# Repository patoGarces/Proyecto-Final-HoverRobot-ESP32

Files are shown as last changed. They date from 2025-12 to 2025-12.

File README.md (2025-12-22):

<h1 align="center">Universidad Nacional de Lomas de Zamora - Facultad de Ingeniería</h1>

Logo Institucional

<h1 align="center">HoverRobot ESP32</h1>

<p align="center">
  <br>
  <em>Estabilización y control</em>
</p>

<p align="center">
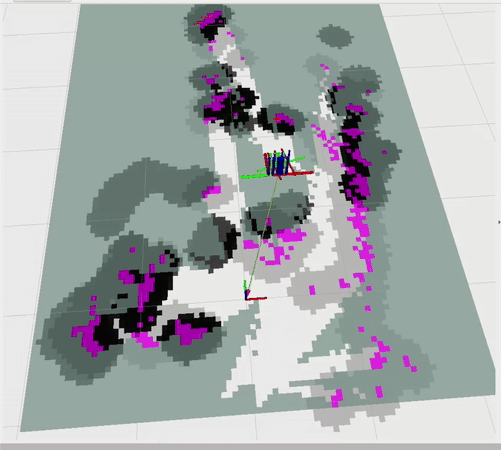
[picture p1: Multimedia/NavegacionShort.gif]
  <br>
  <em>Navegación autónoma con ROS2</em>
</p>

<p align="center">
  <a href="https://www.youtube.com/watch?v=PdzagmnXbF4" target="_blank">
    
  </a>
  <br>
  <em>Demo HoverRobot</em>
</p>

## Introducción / Objetivo

La **Facultad de Ingeniería de la UNLZ** promueve proyectos orientados a la robótica, control y automatización.  
Este repositorio corresponde al **Proyecto Final de Ingeniería Mecatrónica**, cuyo desarrollo se centra en un robot de balanceo autónomo denominado **HoverRobot ESP32**.

El objetivo principal es **convertir la estructura de un hoverboard en una plataforma robótica inteligente**, integrando:

- Un **sistema de control dinámico** basado en **ESP32**.  
- Un **sensor inercial** para mantener el equilibrio.  
- Un módulo de **visión estéreo** basado en una **cámara PS5 + Raspberry Pi 5**.  
- Una **aplicación móvil** para control manual.  

El proyecto explora la interacción entre **estabilidad dinámica**, **visión en tiempo real** y **navegación autónoma** mediante ROS 2.

---

## Índice

- [Descripción](#descripción)
- [Alcance y estado actual](alcance-y-estado-actual)
- [Arquitectura general](#arquitectura-general)
- [Planificación](#planificación)
- [Tecnologías Utilizadas](tecnologias-utilizadas)
- [Listado de Componentes](#listado-de-componentes)
- [Cálculos](#cálculos)
- [Esquemáticos](#esquemáticos)
- [Diseño mecánico y planos](#diseño-mecánico-y-planos)
- [Instrucciones de Uso](#instrucciones-de-uso)  
- [Autor](#autor)  
- [Repositorios Relacionados](#repositorios-relacionados)

---

## Descripción

**HoverRobot** es un robot autoequilibrado que combina electrónica embebida, control dinámico y visión computacional.  
El proyecto nace como una plataforma de estudio para integrar conocimientos de **control**, **electrónica**, **visión artificial**, y **robótica móvil**, culminando en un prototipo **totalmente funcional** y con navegación reactiva para evasión de obstáculos.

---

## Alcance y estado actual

### Objetivos logrados

- Robot de balanceo totalmente funcional.
- Deteccion de profundidad a partir de una camara stereo
- Control manual mediante app móvil.  
- Comunicación estable entre todos los subsistemas.
- Mapeo 2D real mediante SLAM.  
- Navegación basada en visión estéreo. 
- Pruebas en entornos reales con detección de obstáculos.

### Limitaciones actuales y oportunidades de mejora

- El **mapa presenta drift acumulado**, principalmente por la ausencia de un **magnetómetro**, lo que afecta la estabilidad del yaw en la odometría visual.  
- El **campo de visión reducido** de la cámara PS5 limita la cantidad de características detectables, afectando el desempeño del **scan matching de slam_toolbox** y reduciendo la calidad del mapeo.  
- El control basado en PID, aunque funcional, no se adapta automáticamente a variaciones en la dinámica del robot (cambios de peso, centro de gravedad, carga o variaciones en la tracción efectiva de las ruedas). Como mejora futura, podrían evaluarse métodos más robustos como LQR, MPC, control adaptativo o gain scheduling.

---

## Arquitectura general

El sistema se compone de tres subsistemas principales:

### 1. Control de balanceo (ESP32)

- Placa electrónica personalizada con **ESP32**.  
- Lectura de un **IMU MPU6050** para estimar la inclinación del robot.  
- Control directo de los **motores brushless** del hoverboard.  
- Indicadores de estado mediante **WS2812 LEDs**.

### 2. Visión y navegación (Raspberry Pi + ROS 2)

- La **cámara estéreo PS5** captura imágenes del entorno.  
- La **Raspberry Pi 5** procesa la visión y ejecuta nodos ROS 2 para:
  - Rectificación estéreo  
  - Cálculo de disparidad  
  - Conversión a nube de puntos o LaserScan  
  - SLAM con *slam_toolbox*  
  - Planificación y navegación  
- Permite construir un **mapa 2D** del ambiente usando únicamente visión.

### 3. Interfaz y comunicaciones

- **Aplicación móvil en Kotlin** para control manual.  
- Comunicación **TCP** entre Raspberry Pi ↔ ESP32 ↔ App.  
- El robot funciona como **punto de acceso WiFi**, permitiendo conectarse desde una notebook para:
  - **visualizar el mapa en RViz**,  
  - **monitorear datos**,  
  - **lanzar o detener nodos ROS 2**.  

---

## Planificación

### Gantt inicial

<p align="center">
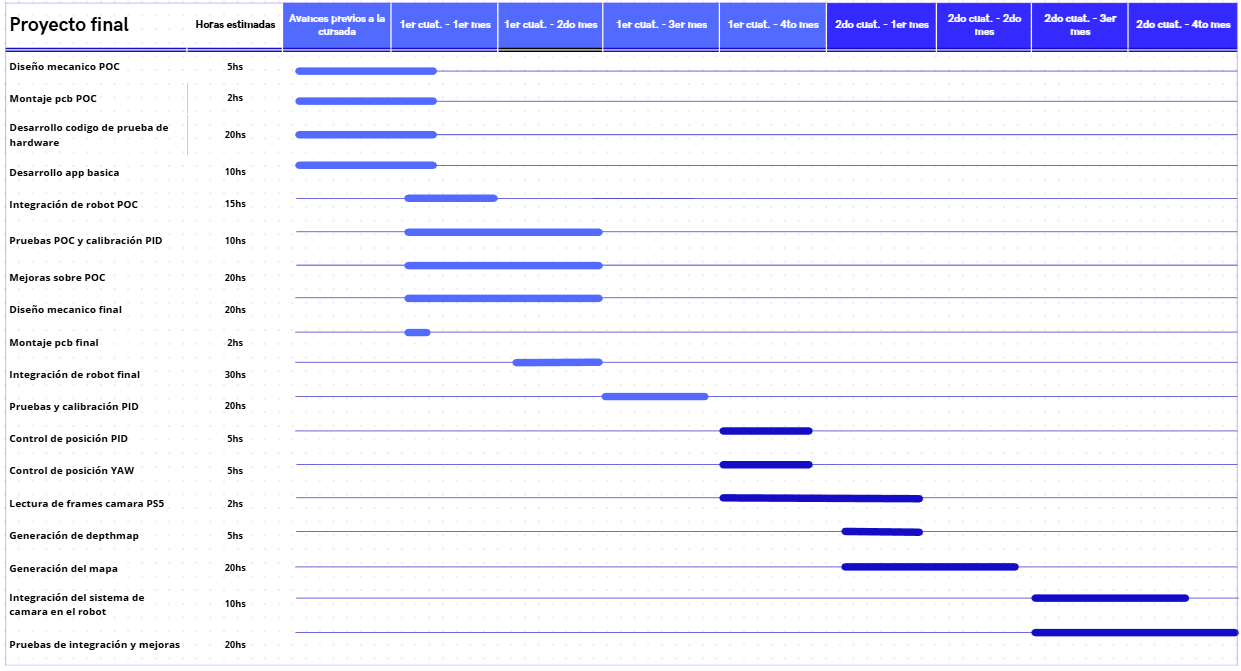
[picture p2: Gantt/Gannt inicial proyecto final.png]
  
  <em>Estimacion inicial: 221hs</em>
</p>

### Gantt final

<p align="center">
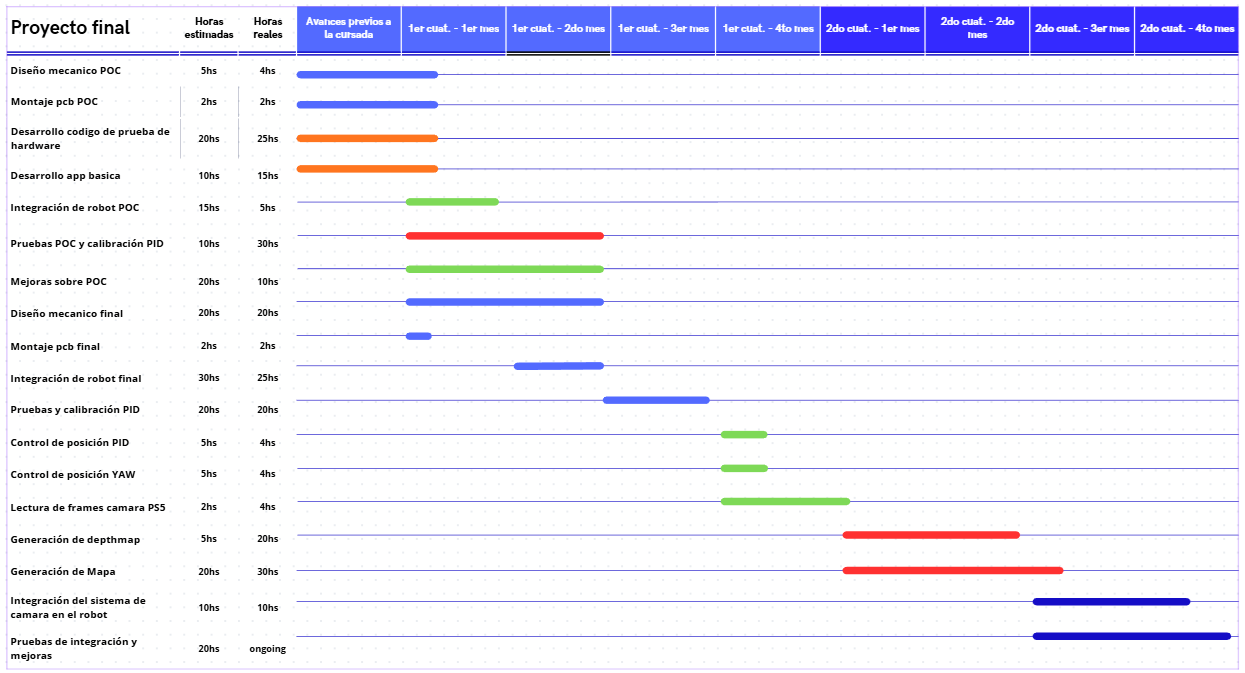
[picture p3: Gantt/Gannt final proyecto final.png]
  
  <em>Total de horas reales: 230hs + ongoing</em>
</p>

Si bien la estimación global fue cercana a la real, algunas tareas puntuales presentaron desvíos significativos debido a problemas técnicos no previstos, cuya resolución demandó más tiempo del estimado inicial.
Estos desvíos se compensaron con otras tareas que resultaron menos complejas de lo esperado.

### Desvío total: +9 h respecto a la estimación inicial

---

## Tecnologías Utilizadas

- **Control y Robótica**: ESP32, controladora hoverboard, motores brushless  
- **Sensado**: IMU MPU6050, cámara estéreo PS5  
- **Computación / Procesamiento**: Raspberry Pi 5, Python, C, Kotlin  
- **Frameworks**: ROS 2 (Jazzy), OpenCV, freeRTOS
- **Comunicación**: TCP sockets, UART  
- **Visión Artificial**: extracción de características, flujo estéreo, navegación basada en percepción  

---

## Listado de Componentes  

### 1. Electrónica del robot (control, regulación, sensores)
| Componente | Cantidad | Precio Unitario (USD) | Precio Total (USD) | Notas |
|---|---|---|---|---|
| ESP32 (montado en placa custom) | 1 | 8 | 8 | Microcontrolador principal |
| Placa perforada / PCB prototipo (custom) | 1 | 3.5 | 3.5 | Base para montar ESP32, sensores y electrónica |
| IMU MPU6050 | 1 | 2 | 2 | Sensor de aceleración y giroscopio |
| Step Down HV | 2 | 4 | 8 | Regulación de tensión |
| Módulo LED WS2812 (8 LEDs) | 1 | 2 | 2 | Indicador de estado visual |
| Cableado + conectores | — | 10 | 10 | JST, Dupont, termocontraíble, etc. |

### 2. Hardware del robot (estructura y montaje)
| Componente | Cantidad | Precio Unitario (USD) | Precio Total (USD) | Notas |
|---|---|---|---|---|
| Hoverboard reutilizado | 1 | 30 | 30 | Motores brushless + controladora + Bateria |
| Perfiles de aluminio 40×40×200 | 2 | 3 | 6 | Estructura |
| Base de fibrofacil | 2 | 5 | 10 | Placas de montaje |
| Rollo de filamento PLA 1 kg | 1 | 12 | 12 |  |
| Tornillería variada | — | 10 | 10 | Ensamblaje |

### 3. Computadora, visión y periféricos
| Componente | Cantidad | Precio Unitario (USD) | Precio Total (USD) | Notas |
|---|---|---|---|---|
| Raspberry Pi 5 | 1 | 100 | 100 | Nodo principal ROS 2 |
| Cámara estéreo PS5 | 1 | 30 | 30 | Visión estéreo |
| Antena WiFi externa | 1 | 5 | 5 |  |
| Conversor USB–Serie | 1 | 2 | 2 | Comuniacion con Raspberry Pi |
| Cable USB-C de alimentación (para Raspberry Pi) | 1 | 5 | 5 |  |

### 4. Totales

| Categoría | Subtotal (USD) |
|---|---|
| Electrónica | 33.5 | 
| Hardware del robot | 68 |
| Computadora y visión | 142 |
| **Total general** | 243.5 |

---

## Cálculos

En la carpeta [`Calculos`](./Calculos) se documentan los principales cálculos utilizados en el proyecto, tanto a nivel de control como de hardware.

Se incluyen:
- Cálculos para la obtención de **posición, velocidad y yaw** a partir de los sensores Hall de las ruedas.
- Descripción de la **fusión del yaw** estimado por encoders con el yaw proveniente del **IMU**.
- **Memoria de cálculo del sistema de alimentación**, donde se detalla el dimensionamiento de las fuentes a partir del consumo de cada subsistema.

Esta sección complementa la implementación práctica del robot, mostrando el criterio de diseño detrás de las decisiones tomadas.

## Esquemáticos

### Mainboard
<p align="center">
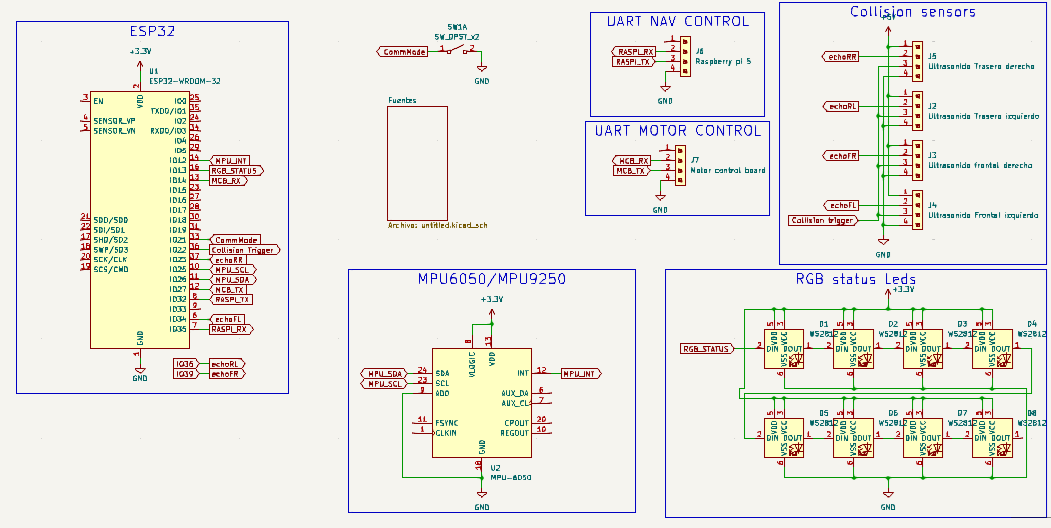
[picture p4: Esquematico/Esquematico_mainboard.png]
  <br>
  <span><em>Esquemático general de la placa de control</em></span>
</p>

### Fuentes
<p align="center">
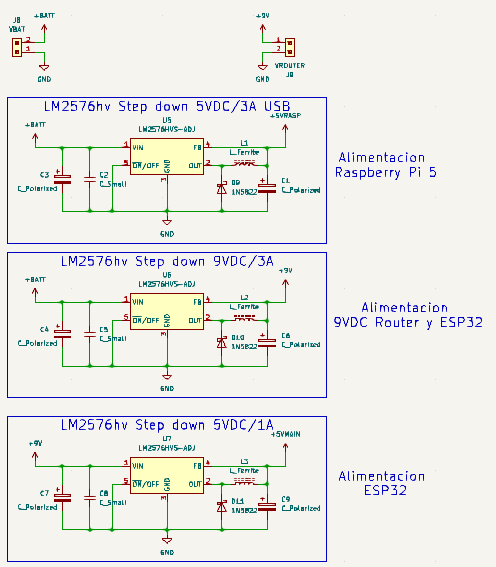
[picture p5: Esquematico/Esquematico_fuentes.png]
  <br>
  <span><em>Esquemático de las fuentes de alimentación</em></span>
</p>

---

## Diseño mecánico y planos

El diseño mecánico del robot fue desarrollado en CAD con SolidWork y documentado en archivos de fabricación, priorizando una estructura simple, modular y fácil de reproducir.

<p align="center">
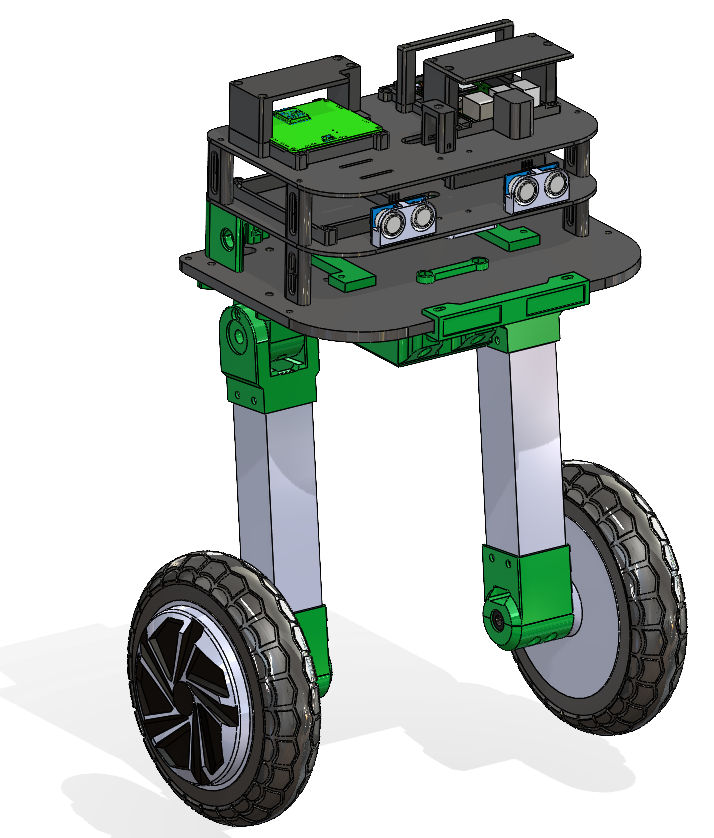
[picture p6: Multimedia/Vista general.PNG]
  <br>
  <em>Vista general del robot</em>
</p>

En el repositorio se incluyen:
- **Modelos STL** de las piezas impresas en 3D, fabricadas en **PLA**.
- **Planos 2D en PDF** para corte láser correspondientes a las **tres bases estructurales**, diseñadas en **fibrofácil**:
  - Base inferior: **9 mm** de espesor  
  - Bases superior e intermedia: **3 mm** de espesor  

Los archivos completos de diseño y fabricación se encuentran disponibles en la carpeta [Planos - 3D](Planos%20-%203D)

## Instrucciones de Uso

1. **Clonar este repositorio** y los repositorios asociados al proyecto.  
2. **Montar el hardware** siguiendo los planos y diagramas disponibles en la carpeta `Esquematico`.  
3. **Cargar el firmware del ESP32** siguiendo las instrucciones detalladas en el repositorio:  
   [HoverRobot-ESP32 (Mainboard)](https://github.com/patoGarces/HoverRobot-ESP32)
4. **Instalar y configurar la aplicación móvil**, según la guía incluida en:  
   [HoverRobotApp](https://github.com/patoGarces/HoverRobotApp-balancing-robot/)
5. **Ejecutar los nodos de visión, SLAM y navegación en ROS 2**, siguiendo los pasos del repositorio:  
   [HoverRobotNavigation](https://github.com/patoGarces/HoverRobotNavigation)
6. **Realizar pruebas** primero en entorno controlado y luego en condiciones reales, verificando estabilidad, detección de obstáculos y mapa generado.

---

## Autor

Proyecto realizado por **Patricio Garcés** como Trabajo Final de la carrera **Ingeniería Mecatrónica**,  
Facultad de Ingeniería – Universidad Nacional de Lomas de Zamora.

---

## Repositorios Relacionados  

- **Mainboard (ESP32)** → [HoverRobot-ESP32](https://github.com/patoGarces/HoverRobot-ESP32)  
- **Aplicación móvil (Kotlin)** → [HoverRobotApp-balancing-robot](https://github.com/patoGarces/HoverRobotApp-balancing-robot/)  
- **Navegación en ROS 2** → [HoverRobotNavigation](https://github.com/patoGarces/HoverRobotNavigation)
- **Firmware de la controladora (fork modificado)** → [hoverrobot-firmware-hack-FOC](https://github.com/patoGarces/hoverrobot-firmware-hack-FOC)

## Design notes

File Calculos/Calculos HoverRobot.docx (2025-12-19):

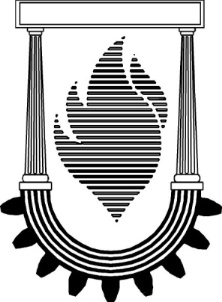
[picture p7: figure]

2° Cuatrimestre 2025

UNIVERSIDAD NACIONAL DE LOMAS DE ZAMORA

FACULTAD DE INGENIERÍA

Cálculos Proyecto Final HoverRobot

Ingeniería Mecatrónica

Alumno:

Patricio Garces (DNI: 39.919.131)

Docentes:

Ing. Cristian Leandro Lukaszewicz

Ing. Ezequiel Blanca

Ing. Juan Ignacio Szombach

# Cálculos

Cálculos a partir de sensores Hall

- Cada rueda tiene 3 sensores de efecto hall desfazados 120 grados, que proporcionan una resolución de 90 pulsos por revolución, con un diámetro de rueda de 17cm, a partir de allí se calcula la velocidad en m/s y la posición en metros:
- Distancia por revolución:

DIST_PER_REV=0.17m*π=0.5310707511m

- Conversión de posición en pasos(posHalls) a metros:

posInMeters=(posHalls)/90.00*DIST_PER_REV

- Conversión de RPM a m/s:

Velocidad [m/s]=(RPM*DIST_PER_REV)/60.00

- Conversión de m/s a RPM:

Velocidad [RPM]=(Vel(m/s)*60.00)/(DIST_PER_REV)

Cálculos eje YAW

El eje YAW, por la naturaleza del acelerómetro y del robot que se encuentra con el sensor en la base paralela al piso, solo se obtiene a partir del giróscopo, lo que genera deriva o drift, que termina afectando de manera negativa la navegación del robot, por ello, para intentar reducir esta deriva, se calcula el valor del YAW a partir de los sensores hall(Posicion) de las ruedas, para terminar fusionando ambos valores, obteniendo una mejor performance:

Para obtener el valor del Yaw(Relativo) a partir de los hall primero se debe conocer:

- Distancia entre ruedas (ancho del robot): 0.32m

Calculando:

enc_yaw_theta(rad) =enc_yaw_theta+((posInMetersR-posInMetersRant)-(posInMetersL-posInMetersLant))/(0.32m)

Conversión a grados:
enc_yaw_theta(rad)=enc_yaw_tetha(rad)* 180.00/π

Fusión de sensores:

- Primero se debe establecer una ponderación entre ambas medidas, en mi caso confío más en la medición del IMU, por lo que le doy una ponderación del 90%: FUSE_APHA_YAW = 0.9

Entonces se calcula:

actualYaw =FUSE_ALPHA_YAW* imuYaw+(1.00-FUSE_ALPHA_YAW)*enc_yaw_theta

Cálculo y Dimensionamiento del Sistema de Alimentación

El sistema utiliza una batería principal de 42 V, por lo que fue necesario diseñar una etapa de regulación capaz de alimentar de forma estable los distintos subsistemas del robot.

Con el objetivo de mejorar la estabilidad y aislar cargas críticas, se decidió dividir la alimentación en dos fuentes independientes, ambas basadas en reguladores de tipo step down:

- Fuente 1: Raspberry Pi 5 + cámara estéreo PS5
- Fuente 2: Electrónica auxiliar (ESP32, router WiFi, LEDs y sensores)

Fuente 1 – Alimentación de Raspberry Pi 5 y cámara estéreo

Consumo Raspberry Pi 5

- Tensión de alimentación: 5 V
- Corriente máxima especificada: 5 A (este valor contempla el consumo máximo incluyendo periféricos USB).

Potencia máxima teórica:

P = V × I

P = 5 V × 5 A = 25 W

Consumo cámara estéreo PS5

- Tensión de alimentación: 5 V
- Corriente estimada: 500 mA

Potencia:

P = 5 V × 0.5 A = 2.5 W

Consumo total teórico Fuente 1

Potencia total:

25 W + 2.5 W = 27.5 W

Corriente equivalente a 5 V:

I = 27.5 W / 5 V = 5.5 A

La cámara estéreo se alimenta desde la misma fuente, considerando que su consumo forma parte del consumo total de corriente de la Raspberry Pi.

Mediciones reales de consumo

Durante las pruebas del sistema se realizaron mediciones directas de corriente en la línea de 5 V, observándose que:

- El consumo real de la Raspberry Pi 5 no superó los 3 A en ningún escenario, incluso con procesamiento de visión activo.
- El consumo de la cámara (~500 mA) se encuentra incluido dentro del margen operativo observado.

Esto confirma que el consumo real es significativamente menor al valor máximo teórico indicado por el fabricante.

Selección del regulador y limitaciones

Para esta fuente se utilizó un módulo basado en LM2576HV, seleccionado principalmente por:

- Su capacidad de soportar tensiones de entrada elevadas (42 V)
- Disponibilidad comercial en formato módulo.

Si bien el consumo real medido se mantiene por debajo de este umbral, el regulador opera cerca de su límite teórico, especialmente considerando:

- La alta relación entre tensión de entrada y salida
- La disipación térmica involucrada.

Este regulador no es el ideal, pero en base a lo disponible en el mercado local, y validado mediante la medición del consumo real, se decidió utilizarlo de todas maneras ante la falta de mejores opciones.

Fuente 2 – Alimentación de la placa principal del robot y los periféricos

Cálculo teórico de consumo:

Router WiFi

- Tensión: 9 V
- Corriente: 600 mA

Potencia:

P = 9 V × 0.6 A = 5.4 W

ESP32 (con WiFi activo)

- Tensión: 5 V
- Corriente pico estimada: 500 mA

Potencia máxima:

P = 5 V × 0.5 A = 2.5 W

Tira de leds WS2812 (8 leds)

- Tensión: 5 V
- Corriente máxima por LED: 60 mA

Corriente total:

I = 8 × 60 mA = 480 mA

Potencia:

P = 5 V × 0.48 A = 2.4 W

Sensores ultrasónicos (4 en total)

- Tensión: 5 V
- Corriente por sensor: 15 mA

Corriente total:

I = 4 × 15 mA = 60 mA

Potencia:

P = 5 V × 0.06 A = 0.3 W

Resumen de consumo Fuente 2

Dispositivo | Potencia aproximada
Router WiFi | 5.4 W
ESP32 | 2.5 W
WS2812 (8 LEDs) | 2.4 W
Sensores ultrasónicos | 0.3 W
Total | 10.6 W

Corriente equivalente a 5 V:

I = 10.6 W / 5 V ≈ 2.1 A

Mediciones reales de consumo

Durante la operación normal del sistema se observó que:

- El ESP32 rara vez alcanza su corriente pico.
- Los LEDs no operan permanentemente al 100 % de brillo
- El consumo total se mantiene por debajo del escenario máximo calculado.

Las mediciones confirmaron un margen adecuado respecto a la capacidad del regulador.

Selección del regulador

Para esta fuente se utilizó un segundo módulo LM2576HV, alimentado desde la batería de 42 V igual que el primero.

Conclusión general

El análisis teórico de consumos, complementado con mediciones reales, permitió validar el diseño de un sistema de alimentación dividido en dos fuentes independientes.

Esta arquitectura mejora la estabilidad del sistema, reduce interferencias entre subsistemas y se adapta a las restricciones impuestas por la alta tensión de la batería principal, utilizando componentes disponibles comercialmente.

Consumo de los motores

Metodología de medición

El consumo del sistema de tracción (compuesto por los motores, la placa de control y la batería original de hoverboard) se midió utilizando los sensores de corriente integrados en la propia placa de potencia.

Estos valores son transmitidos vía telemetría a la aplicación móvil desarrollada para el proyecto, lo que permite visualizar y registrar el consumo en tiempo real sin instrumentación externa adicional.

La medición se realizó en dos condiciones principales:

- Régimen estabilizado: con el robot manteniendo el equilibrio sin desplazamiento significativo.
- Desplazamiento: con el robot realizando movimientos controlados.

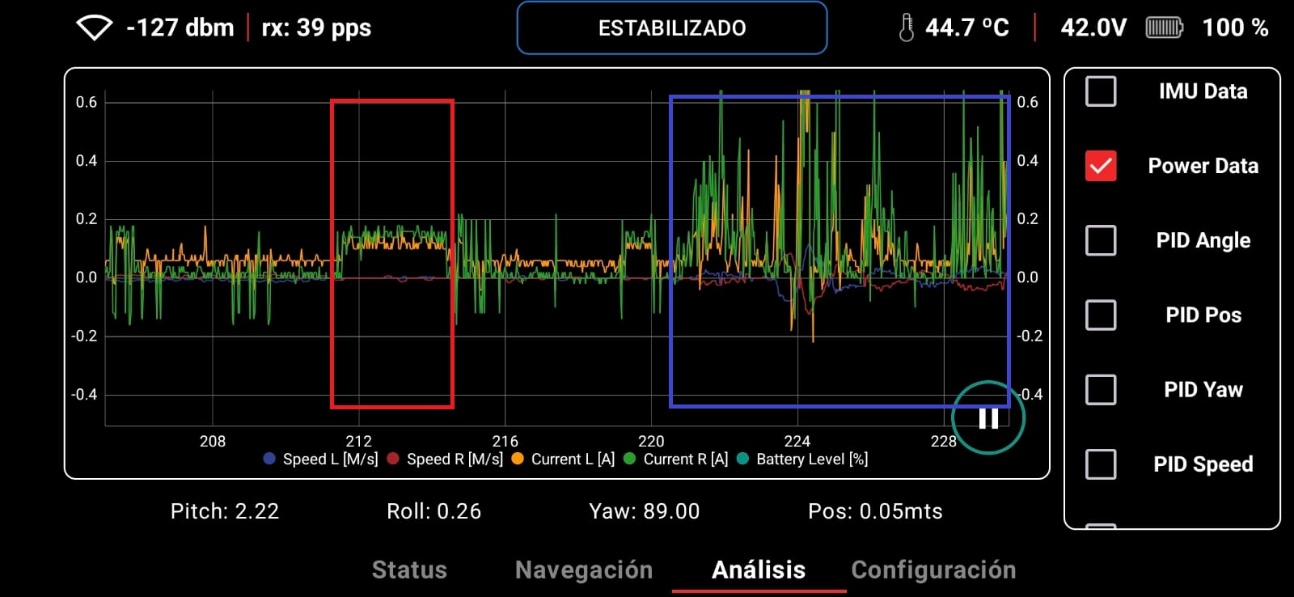
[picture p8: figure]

Gráfico de corriente en tiempo real a través de la HoverRobotApp

En la captura de la aplicación móvil, podemos apreciar:

- En rojo: Consumo correspondiente al estado de equilibrio.
- En azul: Consumo durante el desplazamiento.

En este último caso se observan principalmente picos de corriente, con una señal dominada por variaciones rápidas que se asemejan a ruido, lo que dificulta la extracción de un valor promedio representativo a partir de esa medición.

Resultados obtenidos

Durante el estado estabilizado, el consumo de corriente informado por la placa fue del orden de:

Corriente promedio en equilibrio= ~0,2 A

Potencia estimada

La potencia eléctrica consumida por el sistema de tracción en régimen estabilizado se estima como:

P=V⋅I=42V* 0.2A=8.4W

Consideraciones sobre la medición

Si bien el valor medido resulta bajo y puede generar dudas iniciales, es consistente con un escenario de equilibrio estable, sin aceleraciones ni demanda de torque elevada.

Asimismo, la medición durante el desplazamiento presenta una señal dominada por picos y variaciones rápidas, lo que sugiere limitaciones en la resolución temporal y el filtrado de la medición para ese régimen.

Para un análisis energético más detallado podrían realizarse mediciones externas del bus de potencia y bajo condiciones dinámicas controladas; sin embargo, para los objetivos de este proyecto, la caracterización del consumo en equilibrio resulta suficiente y representativa.

UNIVERSIDAD NACIONAL DE LOMAS DE ZAMORA – FACULTAD DE INGENIERÍA Proyecto final Ingeniería Mecatrónica

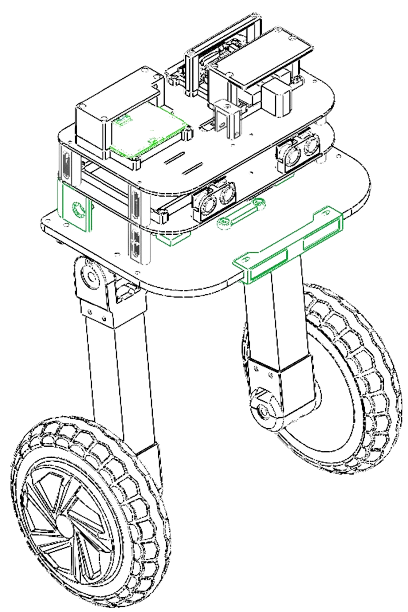
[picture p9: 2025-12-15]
Multimedia/iso_color-removebg-preview.png

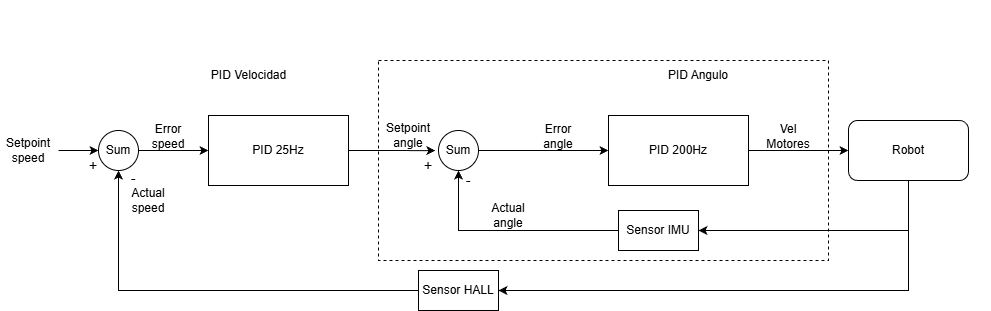
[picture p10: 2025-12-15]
Multimedia/Diagrama de control PID.png

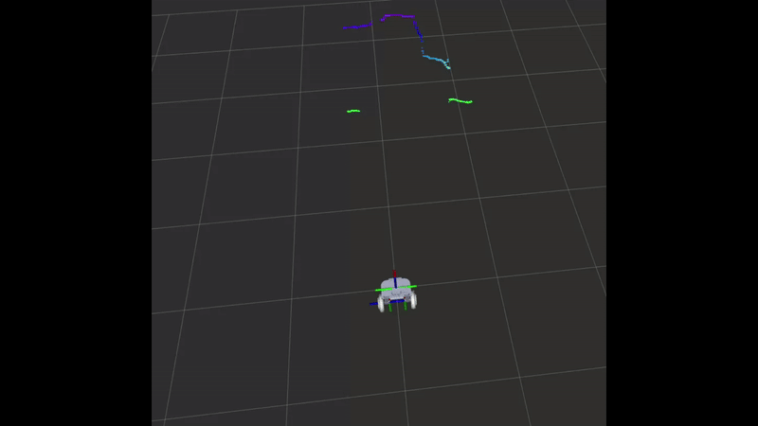
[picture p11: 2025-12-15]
Multimedia/Laserscan.gif

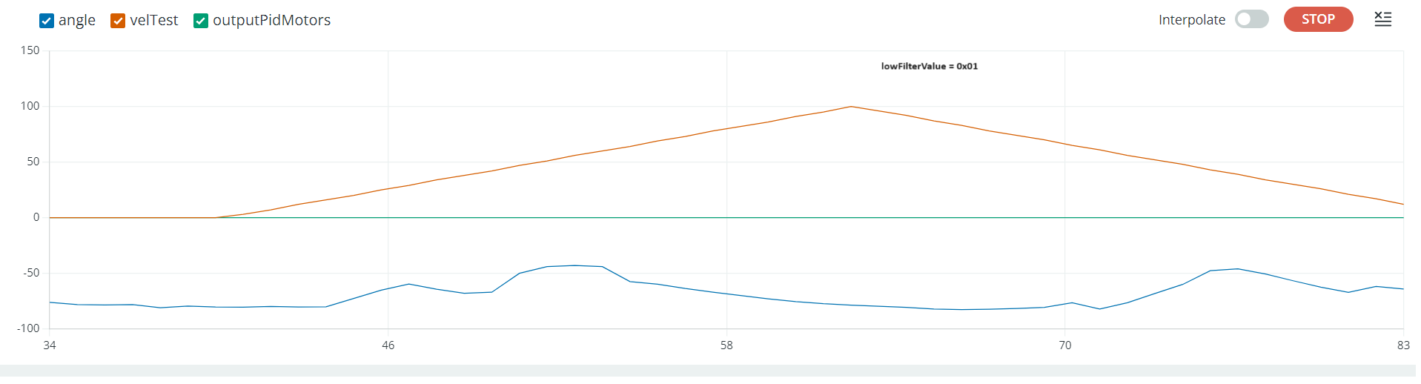
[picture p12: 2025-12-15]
Multimedia/ruido MPU6050.png

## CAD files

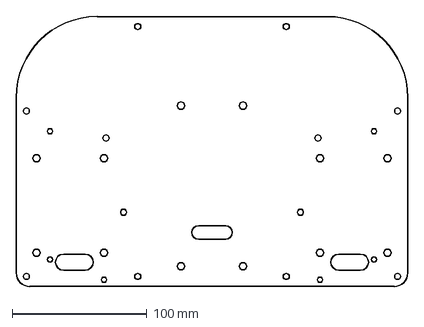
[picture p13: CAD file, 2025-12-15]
Planos - 3D/Fabricacion bases/base v1 - laser.DXF
290.0 x 200.0 mm

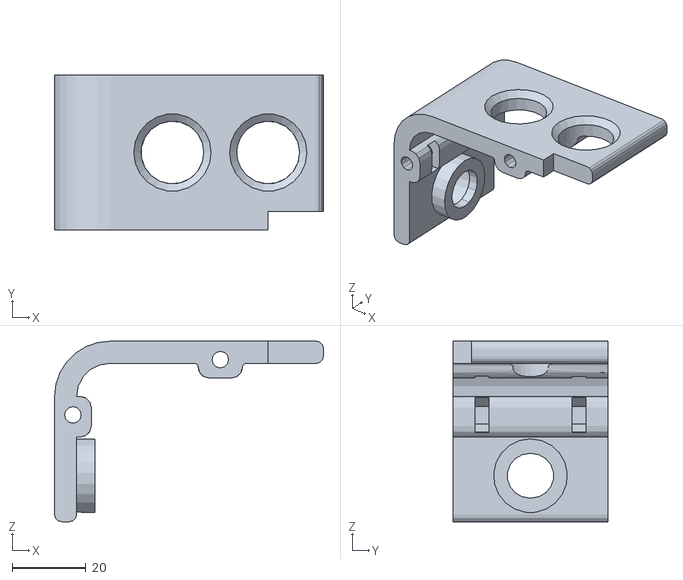
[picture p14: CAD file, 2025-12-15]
Planos - 3D/STLs/soporte lvls V2 - charger.STL
73.0 x 42.0 x 49.0

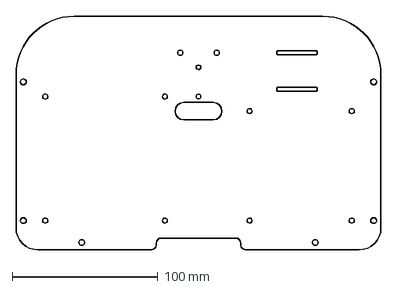
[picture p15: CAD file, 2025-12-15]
Planos - 3D/Fabricacion bases/base lvl3.DXF
250.0 x 160.0 mm

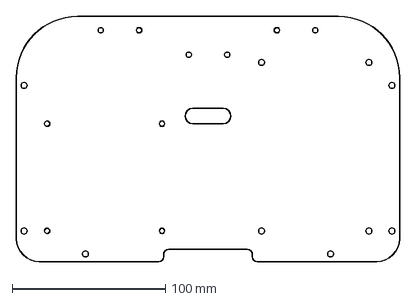
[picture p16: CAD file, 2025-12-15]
Planos - 3D/Fabricacion bases/base lvl2.DXF
250.0 x 160.0 mm

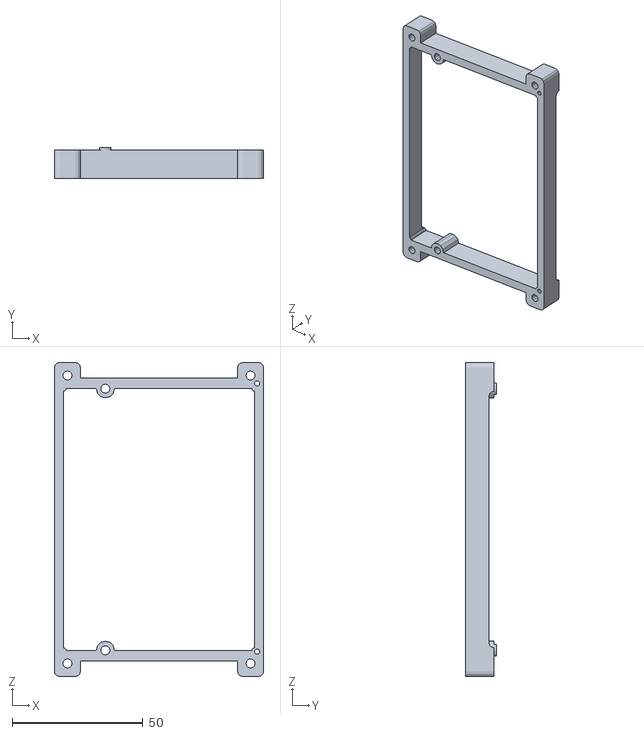
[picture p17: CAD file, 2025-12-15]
Planos - 3D/STLs/Soporte router wifi.STL
80.0 x 12.0 x 120.0

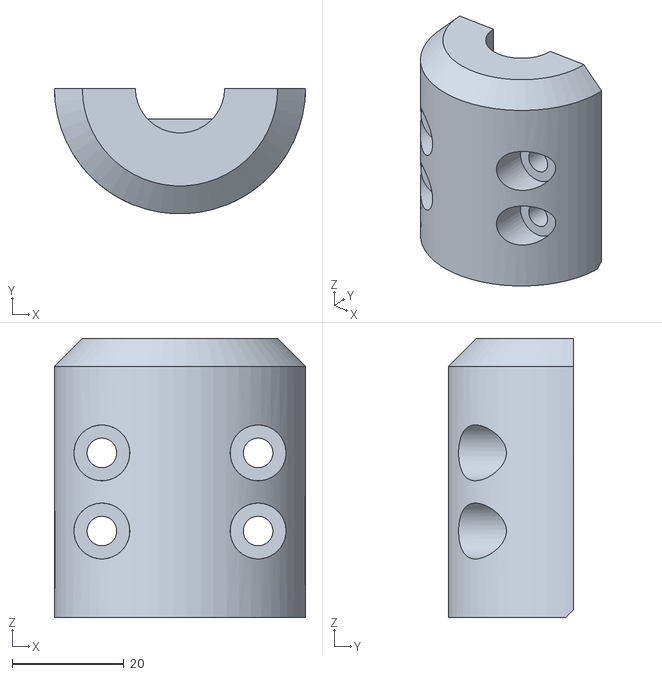
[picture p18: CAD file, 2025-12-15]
Planos - 3D/STLs/soporte rueda v2-b.STL
45.0 x 22.5 x 50.0

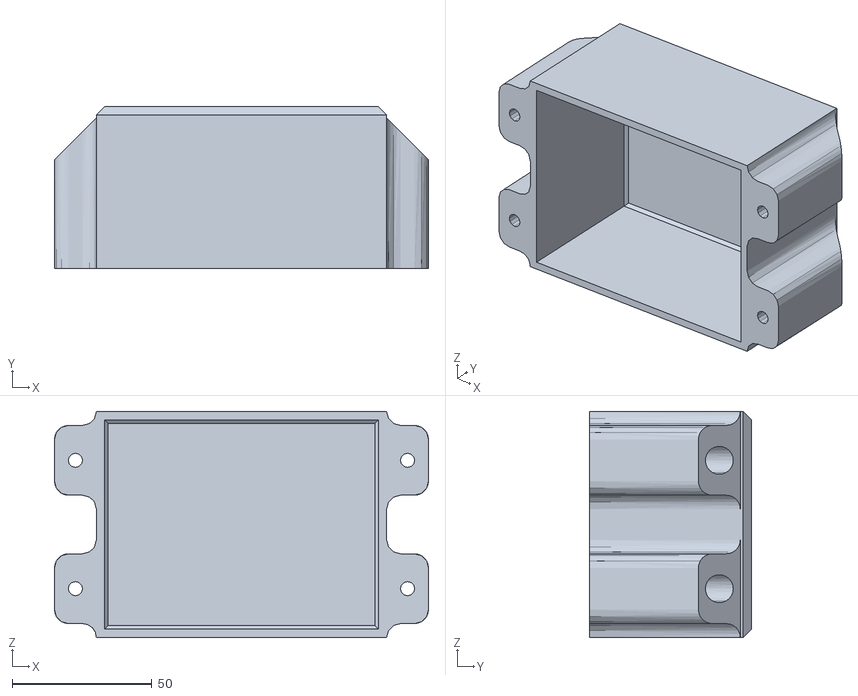
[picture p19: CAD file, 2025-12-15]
Planos - 3D/STLs/soporte_bateriaV2.STL
134.0 x 58.0 x 81.0

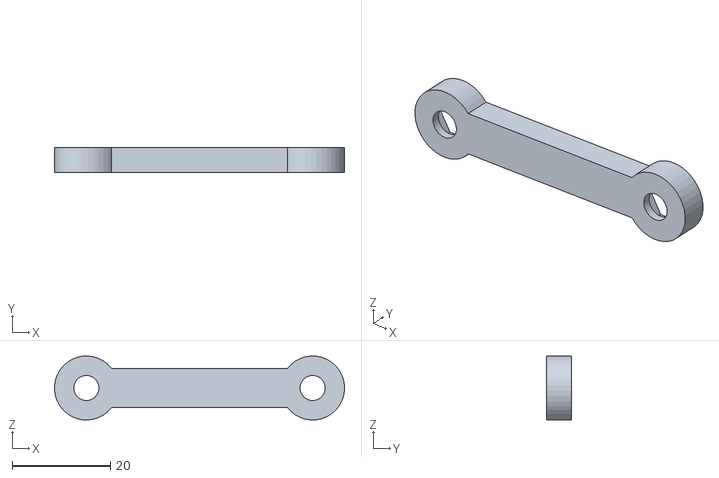
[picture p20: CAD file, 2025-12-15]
Planos - 3D/STLs/soporte tuerca bateria.STL
59.0 x 5.00 x 13.0

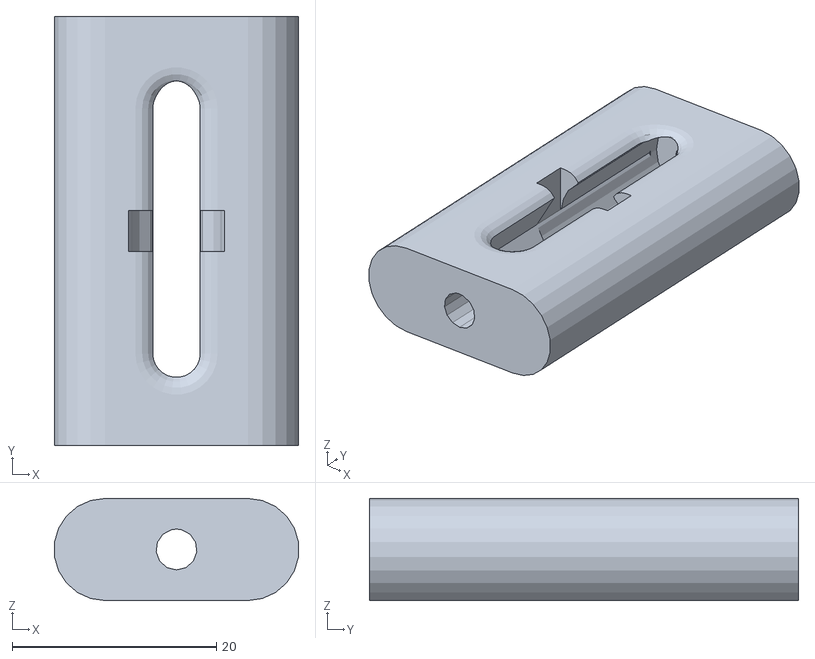
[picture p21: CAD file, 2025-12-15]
Planos - 3D/STLs/soporte lvls C.STL
23.9 x 42.0 x 10.0

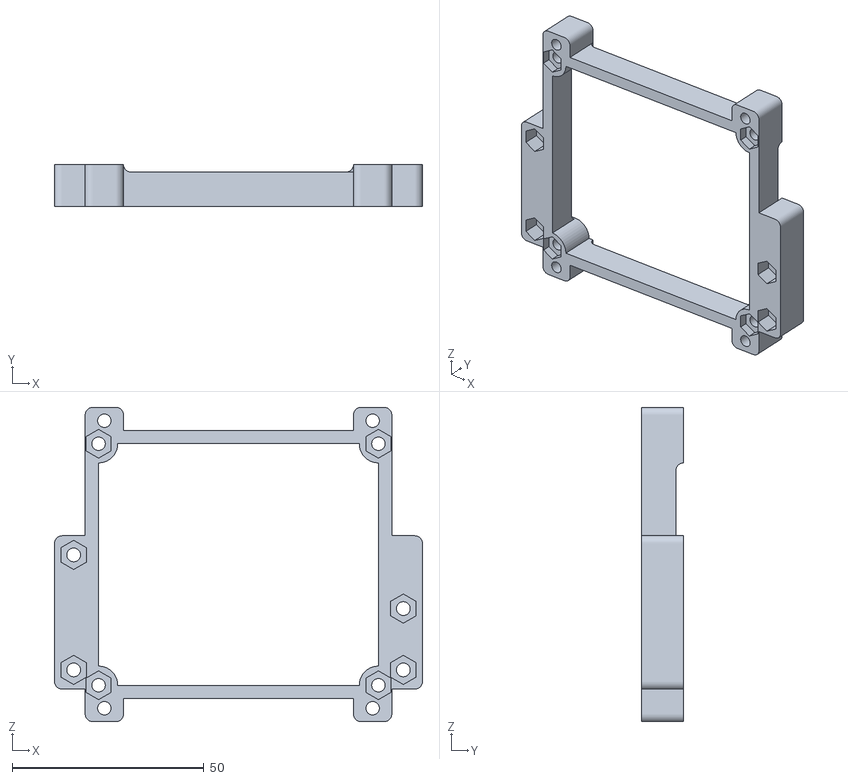
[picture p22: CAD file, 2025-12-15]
Planos - 3D/STLs/soporte IMU-inferior.STL
96.0 x 11.0 x 82.0

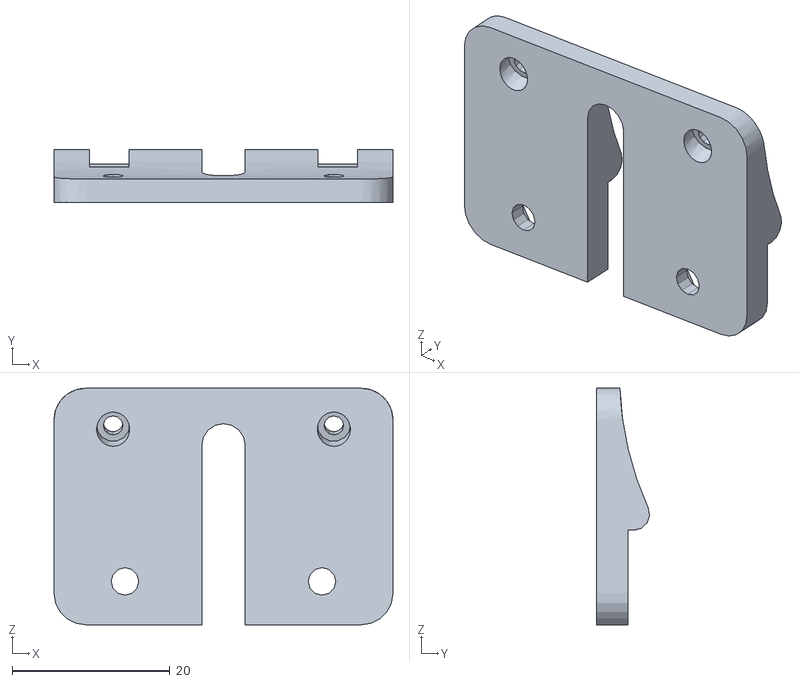
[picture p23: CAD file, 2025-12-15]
Planos - 3D/STLs/soporte camara.STL
43.0 x 6.75 x 30.0

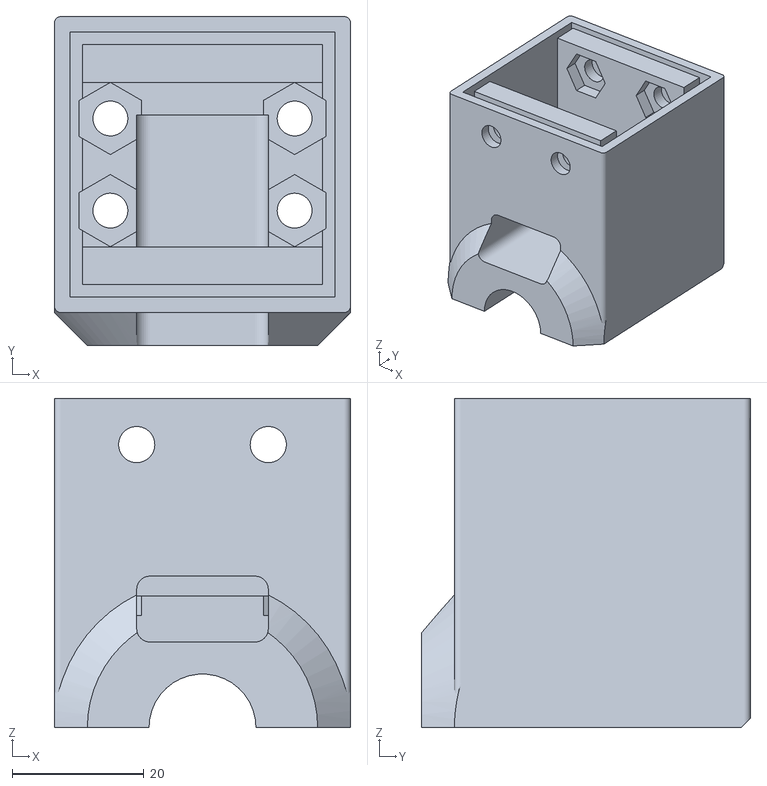
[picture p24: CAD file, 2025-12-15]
Planos - 3D/STLs/soporte rueda v2.STL
45.0 x 50.0 x 50.0

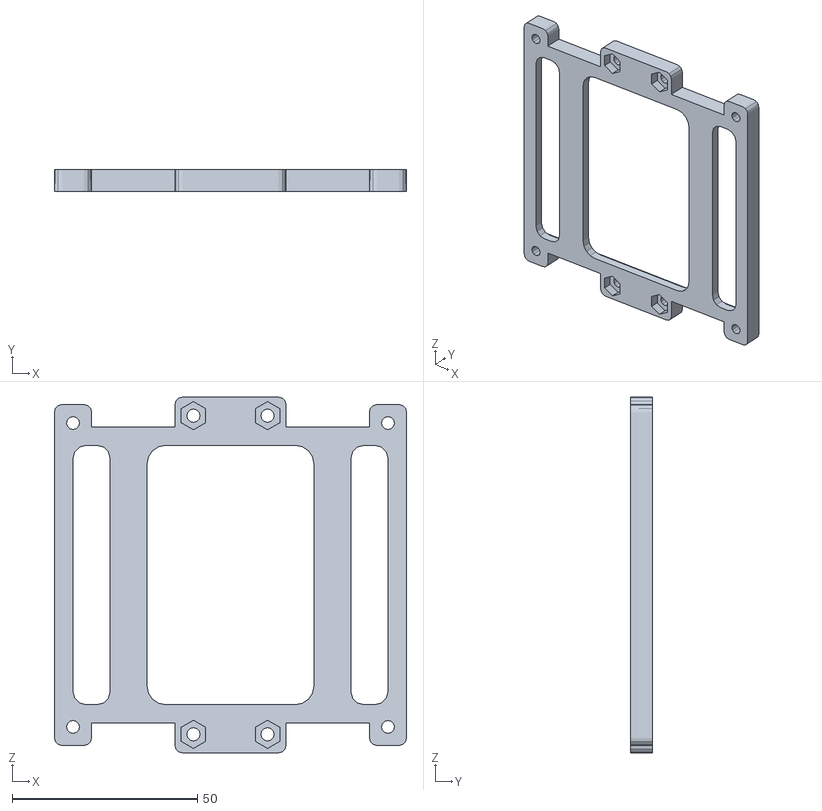
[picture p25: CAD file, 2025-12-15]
Planos - 3D/STLs/soporte raspi inferior.STL
95.0 x 6.00 x 96.0

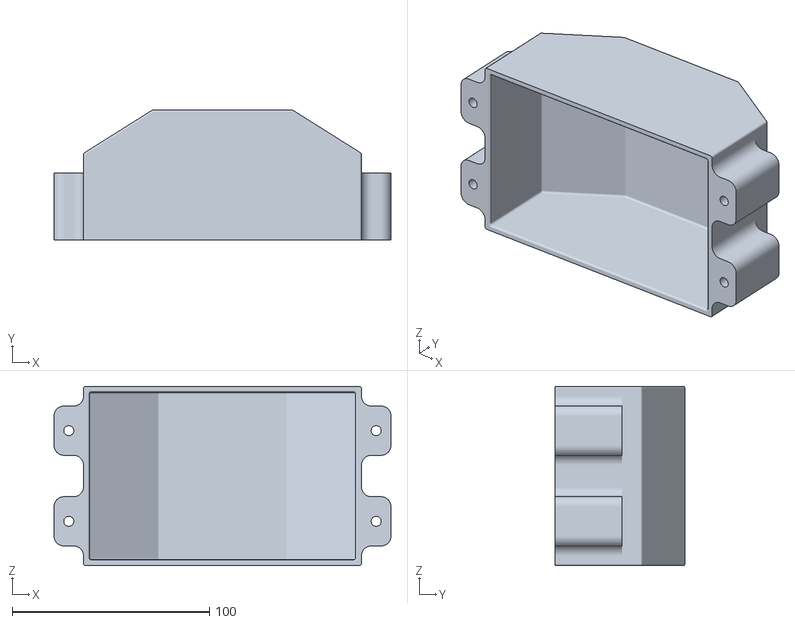
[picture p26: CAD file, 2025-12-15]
Planos - 3D/STLs/soporte_bateria.STL
171.0 x 66.0 x 91.0

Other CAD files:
Planos - 3D/STLs/soporte lvls V2 - poweron.STL
Planos - 3D/STLs/soporte lvls B.STL
Planos - 3D/STLs/soporte base A.STL
Planos - 3D/STLs/soporte lvls.STL
Planos - 3D/STLs/anti impacto V3.STL
Planos - 3D/STLs/soporte - MCB split.STL
Planos - 3D/STLs/soporte IMU-superior.STL
Planos - 3D/STLs/soporte antena wifi.STL
Planos - 3D/STLs/soporte base B.STL
Planos - 3D/STLs/soporte raspi superior.STL
Planos - 3D/STLs/soporte ultrasonido frontal.STL

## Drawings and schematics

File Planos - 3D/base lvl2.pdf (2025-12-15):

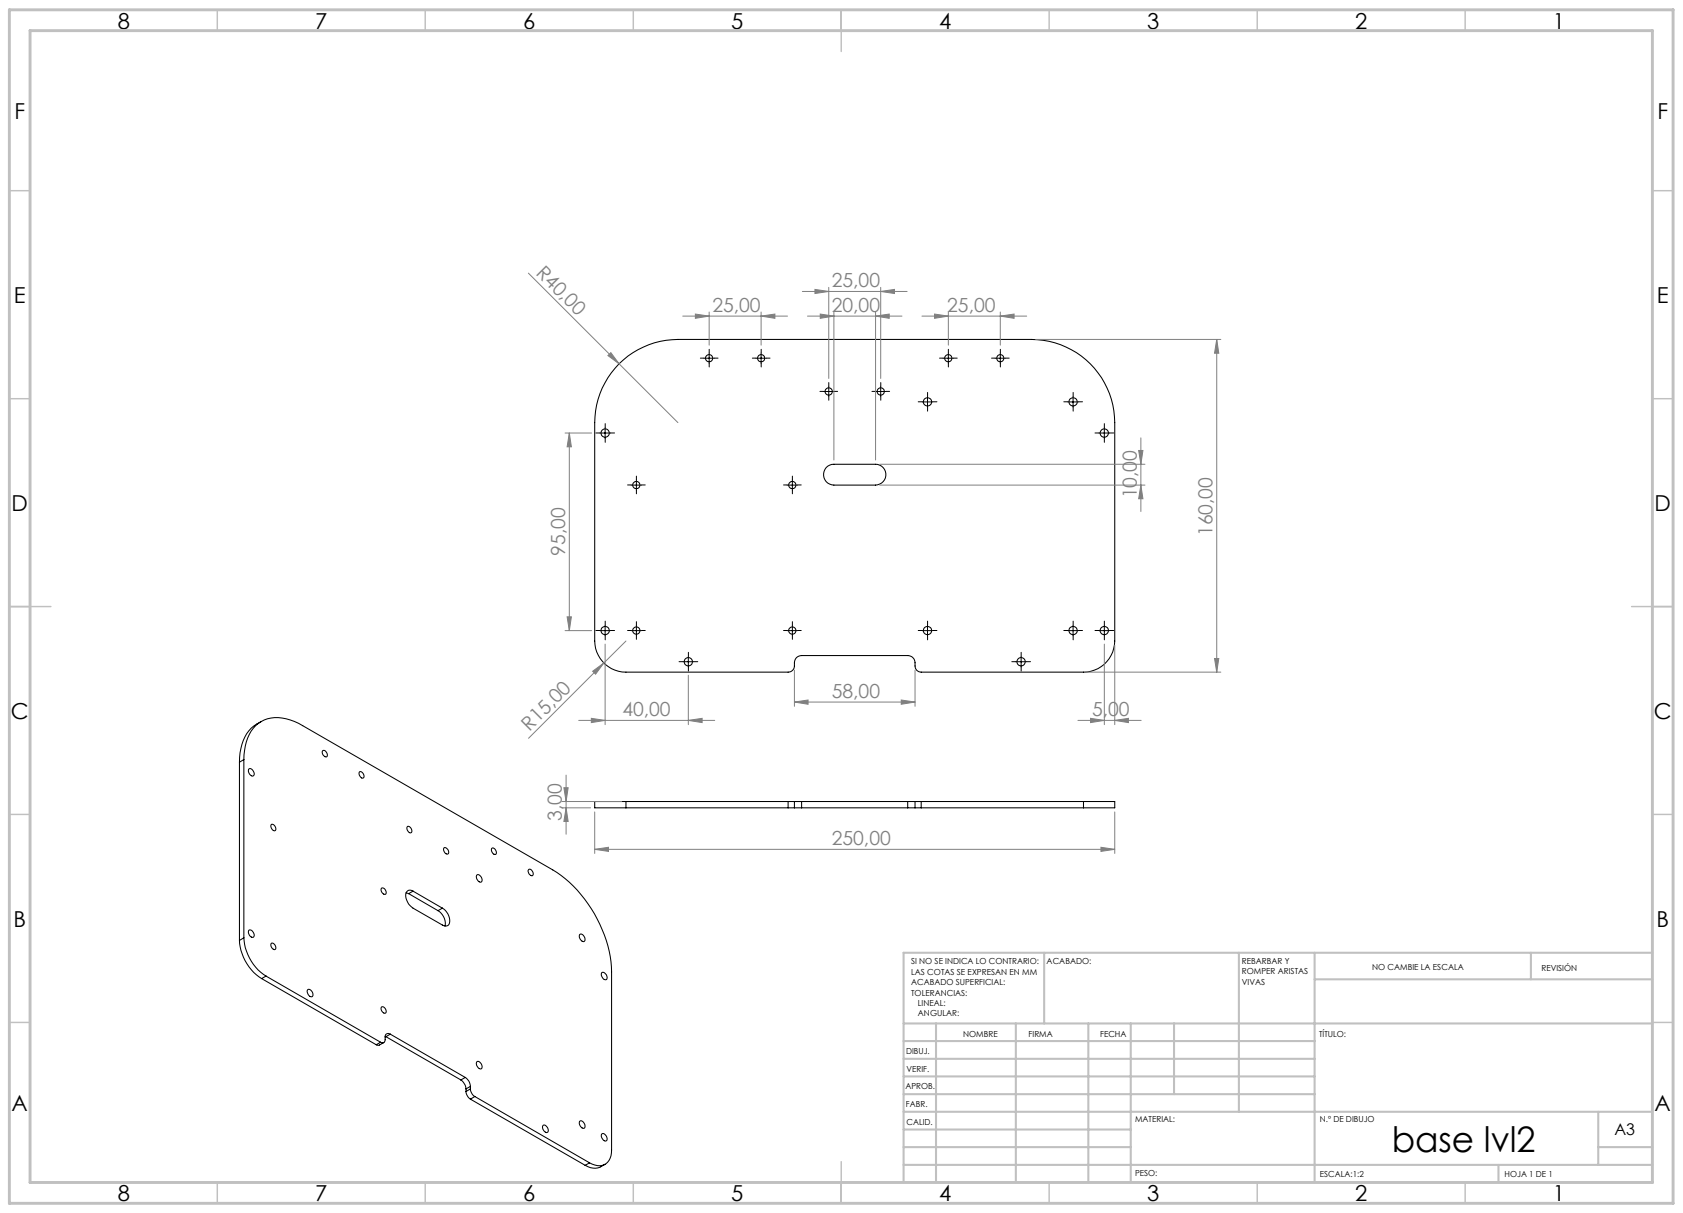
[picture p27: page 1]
ACABADO:; REBARBAR Y; ROMPER ARISTAS; NO CAMBIE LA ESCALA; REVISIÓN; ESCALA:1:2; HOJA 1 DE 1

SI NO SE INDICA LO CONTRARIO:
LAS COTAS SE EXPRESAN EN MM
ACABADO SUPERFICIAL:
TOLERANCIAS:
LINEAL:
ANGULAR:

NOMBRE | FIRMA | FECHA | | | | TÍTULO:

DIBUJ.
VERIF.
APROB.
FABR.
CALID. | | | | MATERIAL: | N.º DE DIBUJO base lvl2 | A3

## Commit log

2025-12-05 Cambio menores en el README.md
2025-12-06 Agrego esquematico y reemplazo gif del readme
    [HoverRobotMain.kicad_pcb, HoverRobotMain.kicad_sch]
2025-12-06 Avances en esquematico
    [HoverRobotMain.kicad_sch, untitled.kicad_sch]
2025-12-11 Agrego imagenes de gannt inciial y final
2025-12-15 Agrego planos y STLs
    [Soporte router wifi.STL, anti impacto V3.STL, base lvl2.DXF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]
2025-12-15 Agrego png de vista general
    [base lvl2.DXF, base lvl3.DXF, base v1 - laser.DXF]
2025-12-15 Agrego datasheet de los componentes
2025-12-15 Actualizo gif de navegacion
2025-12-16 Agrego documentacion de calculos
    Se agrega una descripcion de los calculos realizados para obtener la posicion y velocidad a partir de los sensores hall de las ruedas, el calculo del YAW a partir de los mismos sensores, y la fusion 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
    Ademas se agrega una memoria de calculo para las fuentes de alimentacion del robot
2025-12-16 Agrego seccion de calculo
2025-12-16 Cambios menores en el readme
